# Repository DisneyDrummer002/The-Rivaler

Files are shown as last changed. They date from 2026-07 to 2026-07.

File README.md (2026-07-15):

# The Rivaler

The Rivaler is a multi-controller Arduino robot project with wireless remote control, stepper drive, line following, ultrasonic safety checks, a launcher mechanism, and camera/SD-card control.

> [!CAUTION]
> This project controls moving machinery and a launcher. Read the [safety requirements](docs/safety.md) before powering motors. The wireless software stop is not a substitute for a normally closed, latching physical emergency-stop circuit that removes motor power.

## Repository contents

| Path | Contents |
| --- | --- |
| [`firmware/giga_main_controller`](firmware/giga_main_controller) | Arduino GIGA drive, launcher, line-following, and ultrasonic-safety firmware |
| [`firmware/robot_nano_esp32`](firmware/robot_nano_esp32) | Robot-side Nano ESP32 wireless/UART bridge |
| [`firmware/remote_nano_esp32`](firmware/remote_nano_esp32) | Handheld remote firmware |
| [`firmware/mega_camera_controller`](firmware/mega_camera_controller) | Arduino Mega camera and SD-card controller |
| [`firmware/giga_stepper_test`](firmware/giga_stepper_test) | Standalone GIGA stepper-motor test sketch |
| [`firmware/shared`](firmware/shared) | Shared packet protocol and host-side protocol test |
| [`firmware/libraries/RivalerProtocol`](firmware/libraries/RivalerProtocol) | Arduino library wrapper for the shared protocol |
| [`mactest`](mactest) | Nano ESP32 utility sketch for printing a board's Wi-Fi MAC address |
| [`docs`](docs) | Wiring, protocol, line-following, camera, and safety documentation |
| [`BoM.xlsx`](BoM.xlsx) | Bill of materials |
| [`The Rivaler Connections.drawio.svg`](The%20Rivaler%20Connections.drawio.svg) | Editable Draw.io connection diagram in SVG form |
| [`Prompt Document for The Rivaler.docx`](Prompt%20Document%20for%20The%20Rivaler.docx) | Project prompt and design document |

## Hardware targets

- Arduino GIGA R1 WiFi: main controller and stepper test
- Two Arduino Nano ESP32 boards: remote and robot bridge
- Arduino Mega 2560: Arducam Mega B0401 and SD-card controller

See the [pin map](docs/pin-map.md) and the Draw.io connection diagram before wiring the boards.

## Build notes

Install [Arduino CLI](https://arduino.github.io/arduino-cli/) or use Arduino IDE 2. Install the Arduino Mbed OS GIGA Boards and Arduino ESP32 Boards platforms. The camera controller also requires the official `Arducam_Mega` library described in [the camera documentation](docs/mega-camera.md).

Example Arduino CLI commands for the sketches that do not require the camera library:

```sh
arduino-cli compile --fqbn arduino:mbed_giga:giga firmware/giga_main_controller
arduino-cli compile --fqbn arduino:mbed_giga:giga firmware/giga_stepper_test
arduino-cli compile --fqbn arduino:esp32:nano_nora firmware/robot_nano_esp32
arduino-cli compile --fqbn arduino:esp32:nano_nora firmware/remote_nano_esp32
```

Before uploading, review each sketch's `Config.h`, calibrate the line sensors as documented in [line following](docs/line-following.md), and verify the board addresses and physical wiring.

## Documentation

- [Pin map](docs/pin-map.md)
- [Packet protocol](docs/protocol.md)
- [Line following and calibration](docs/line-following.md)
- [Mega camera and SD card](docs/mega-camera.md)
- [Safety requirements](docs/safety.md)

## Project status

This is active hardware-development firmware. Test with drive wheels raised and launcher motor power disconnected before performing controlled, low-speed floor tests.

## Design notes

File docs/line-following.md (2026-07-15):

# Line Following

The GIGA implements line following as a separate drive mode. Pressing the
remote joystick button toggles the mode. A deliberate joystick movement,
remote timeout, emergency stop, wall warning, or missing-floor warning
cancels it immediately.

The controller independently normalizes the two analog sensors, applies
filtered proportional and derivative steering, slows for larger errors, and
keeps corrections within configured drive limits. If the line disappears, it
briefly continues at reduced speed, then pivots only toward the last observed
line direction. It stops if the line is not reacquired before the search
timeout.

## Sensor Placement

Place the two sensors close enough that the centered line produces a useful
signal on at least one sensor, preferably both. With only two sensors, a line
that passes invisibly through a wide gap between them cannot be distinguished
from a completely lost line.

## Calibration

Keep `kLineSensorCalibrationConfigured` set to `false` until calibration is
complete. The firmware will reject line-following activation in this state.

1. Disconnect motor power or raise the wheels clear of the work surface.
2. Set `kLineSensorCalibrationLoggingEnabled` to `true` and upload the GIGA
   firmware.
3. Hold both sensors over the normal floor. After the filtered readings settle,
   record several `Line sensors raw` values and average each sensor.
4. Repeat with both sensors over the line.
5. Put the four averages into the floor/line reading constants in the GIGA
   configuration. The line may read higher or lower than the floor.
6. Set `kLineSensorCalibrationConfigured` to `true` and calibration logging
   back to `false`.
7. With the robot supported and launcher power disconnected, verify that the
   Line Detected LED responds to the line before conducting a low-speed floor
   test.

The configured floor-to-line span must be at least
`kLineSensorMinimumCalibrationSpan` for each sensor. After basic operation is
verified, steering gains, cruise speed, loss timing, and detection strength can
be tuned in `Config.h` without changing the controller logic.

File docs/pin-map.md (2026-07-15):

# Rivaler Pin Map

This is the initial wiring map for firmware development. Inputs marked
`INPUT_PULLUP` connect to ground when activated. All boards sharing a signal
must share ground, but their power rails remain separate as shown in the
connection diagram.

## Remote Nano ESP32

| Pin | Connection |
| --- | --- |
| A0 | Joystick X |
| A1 | Joystick Y |
| D2 | Quick Shoot button |
| D3 | Rapid Fire button |
| D4 | Take Picture button |
| D5 | Eject SD button |
| D6 | Joystick push / Follow Line button |
| D7 | Launcher arm switch |
| D12 | Wireless software emergency-stop button |
| D8 | Active buzzer signal |
| D9 | Launcher Armed LED |
| D10 | Line Detected LED |
| D11 | Line Following LED |

The Remote Nano uses ESP-NOW with Robot Nano MAC
`3C:84:27:FC:EF:2C`. Its own MAC is `20:6E:F1:32:60:BC`.

The remote uses five discrete buttons: Quick Shoot, Rapid Fire, Take Picture,
Eject SD, and wireless emergency stop. The joystick push switch controls
Follow Line, and the separate switch controls launcher arming.

## Robot Nano ESP32

| Pin | Connection |
| --- | --- |
| D6 | UART RX from GIGA D14 / Serial4 TX3 |
| D7 | UART TX to GIGA D15 / Serial4 RX3 |
| D8 | UART TX to Mega D19 / RX1 |

The Mega-to-Nano UART return wire is intentionally absent.

## Arduino GIGA

| Pins | Connection |
| --- | --- |
| D3, D6 | Shield channel A: enable, speed |
| D4, D5 | Shield channel B: enable, speed |
| D7, D10 | Shield channel C: enable, speed |
| D8, D9 | Shield channel D: enable, speed |
| D14, D15 | Serial4 TX/RX for Robot Nano (board labels TX3/RX3), dedicated UART exception |
| A0, A1 | Left and right line sensors |
| D22, D23 | Front ultrasonic trigger/echo |
| D24, D25 | Downward ultrasonic trigger/echo |
| D26, D27 | Left ultrasonic trigger/echo |
| D28, D29 | Right ultrasonic trigger/echo |
| D30, D31 | Rear ultrasonic trigger/echo |
| D32 | 360-degree positional launcher magazine servo; homes at 0 degrees and indexes 45, 90, 135, 180, -45, -90, -135, then 0 |
| D33, D34, D35 | External launcher H-bridge: IN1, IN2, full-speed enable |

Connect the left bipolar stepper to shield channels A and B, and the right
bipolar stepper to channels C and D. The shield has no remaining H-bridge
channel for the launcher DC motor. The external H-bridge drives that motor
from D33, D34, and D35 instead.

The project's HC-SR04 modules have been verified operating at 3.3 V with the
GIGA, so their Echo signals connect directly to D23, D25, D27, D29, or D31.
The servo signal is D32, but servo power must come from its external supply
with a common ground to the GIGA.

## Arduino Mega

| Pins | Connection |
| --- | --- |
| D19 | UART RX from Robot Nano D8 |
| ICSP: 50/51/52 | Arducam Mega B0401 SPI: MISO/MOSI/SCK |
| D7 | Arducam B0401 chip select |
| ICSP: 50/51/52 | SD module shared SPI bus |
| D4 | SD module chip select |

The Robot Nano's 3.3 V TX signal is acceptable at Mega D19. Do not wire the
Mega's 5 V TX pin back to either Nano. Keep the inactive SPI device's chip
select HIGH to prevent camera/SD bus contention.

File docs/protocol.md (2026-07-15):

# Rivaler Packet Protocol

Protocol version 1 is the shared binary format for both ESP-NOW and UART.
It keeps the remote, bridge, GIGA, and camera controller aligned without
depending on ad-hoc text parsing.

## Packet layout

| Byte(s) | Field | Description |
| --- | --- | --- |
| 0 | Start | `0xA5` |
| 1 | Version | `1` |
| 2 | Type | Message type identifier |
| 3 | Sequence | Sender-local sequence; event retransmissions reuse their original value |
| 4 | Payload length | `0` through `24` |
| 5... | Payload | Binary payload for the packet type |
| Final | Checksum | XOR of bytes 1 through the final payload byte |

Only `6 + payload length` bytes are sent. Every receiver validates start byte,
version, exact received length, payload length, and checksum before acting.

## Transport routes

| Route | Direction | Message types |
| --- | --- | --- |
| Remote Nano ESP32 and Robot Nano ESP32 | Two-way ESP-NOW | Remote control, robot status, acknowledgement |
| Robot Nano ESP32 and Arduino GIGA | Two-way UART | Remote control, robot status, acknowledgement |
| Robot Nano ESP32 to Arduino Mega | One-way UART | Camera command |

The Remote Nano (`20:6E:F1:32:60:BC`) and Robot Nano
(`3C:84:27:FC:EF:2C`) are paired peers. ESP-NOW traffic is bidirectional;
the labels only identify each board's MAC address.

## Message payloads

### `kRemoteControl` (`0x10`)

| Field | Type | Meaning |
| --- | --- | --- |
| `joystickX` | signed 8-bit | `-100` to `100`; left/right command after dead-zone filtering |
| `joystickY` | signed 8-bit | `-100` to `100`; positive is forward |
| `heldButtons` | unsigned 16-bit flags | Current state of arm switch, line-follow button, and emergency stop |
| `edgeEvents` | unsigned 16-bit flags | One-time button presses: quick shoot, rapid fire, take picture, eject SD, line-follow press |

`heldButtons` is sent with every control packet. For packets containing
`edgeEvents`, the Remote Nano retransmits the same sequence until the Robot
Nano acknowledges receipt. The Robot Nano suppresses duplicate sequences, so
retransmission cannot stack launcher or camera actions.

### `kRobotStatus` (`0x20`)

| Field | Type | Meaning |
| --- | --- | --- |
| `statusFlags` | unsigned 16-bit flags | Launcher, line, safety, camera, and SD state |
| `frontDistanceCm` | unsigned 16-bit | Filtered front ultrasonic reading; `0` means unavailable |
| `groundDistanceCm` | unsigned 16-bit | Filtered downward sensor reading; `0` means unavailable |
| `safetyFault` | unsigned 8-bit | Current fail-safe reason, or `kNone` |

### `kCameraCommand` (`0x30`)

| Field | Type | Meaning |
| --- | --- | --- |
| `operation` | unsigned 8-bit enum | Capture burst or prepare SD eject |
| `photoCount` | unsigned 8-bit | Number of photos for a capture burst |
| `intervalMs` | unsigned 16-bit | Delay between photos |

The Robot Nano creates camera commands after receiving applicable remote
events. The Arduino Mega does not send command replies back over this link.

### `kAcknowledgement` (`0x40`)

| Field | Type | Meaning |
| --- | --- | --- |
| `acknowledgedSequence` | unsigned 8-bit | Sequence number being acknowledged |
| `accepted` | unsigned 8-bit | `1` when accepted, `0` when rejected |
| `rejectionReason` | unsigned 8-bit enum | `SafetyFault` value, otherwise `kNone` |

The Robot Nano acknowledges valid remote-control packets that contain one-shot
events. An acknowledgement means the bridge received the packet; it is not
permission to keep moving. The GIGA still stops drive motion and disarms the
launcher when valid remote control packets time out.

## Safety rules at the protocol boundary

- Receivers ignore malformed, stale, unknown-version, or checksum-invalid packets.
- A receiver must never fire or arm based on an incomplete packet.
- The Robot Nano forwards only valid remote-control packets to the GIGA.
- The GIGA is the final authority for drive, safety, arming, and any launcher action.
- The Mega accepts only valid camera-command packets and has no path to control the GIGA.

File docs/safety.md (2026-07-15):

# Safety Requirements

The remote's emergency-stop button on `D12` sends a wireless software stop.
It stops drive motion and disarms the launcher when the GIGA receives it, but
it is not a substitute for a physical emergency stop.

Install a separate normally closed, latching emergency-stop circuit that
removes power from the drive and launcher motor supplies. The circuit must
remain effective if any controller, radio link, or firmware component fails.

The launcher magazine uses positional commands across its configured
-180-degree through 180-degree range. It homes to 0 degrees at startup and
advances through the configured shooting positions. Verify its mechanical
alignment and full travel with launcher motor power disconnected before using
the firing controls.

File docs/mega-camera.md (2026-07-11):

# Mega Camera and SD

The Mega camera controller uses the official `Arducam_Mega` library for the
Arducam Mega B0401. Install that library from the Arduino IDE Library Manager
before compiling the Mega sketch. Do not substitute the older `ArduCAM` library.

The camera and SD card share the Mega hardware SPI bus on the ICSP header. The
camera chip-select is D7 and the SD chip-select is D4. Both are driven HIGH
whenever the other device is accessed.

Valid capture commands are processed as a nonblocking burst. The B0401 creates
QVGA JPEGs, each image is written as `RV00001.JPG` through `RV99999.JPG`, and
existing files are never overwritten. The default manual-photo command creates
10 images at 500 ms intervals. Camera, SD, malformed-JPEG, and receive-timeout
failures abort the active burst and are reported on the Mega USB serial console.

An SD-eject command waits only for the current image to finish, and cancels
any remaining images in the burst. It then closes the file, calls `SD.end()`,
deselects both SPI devices, and reports
`SD card is safe to remove.` on the Mega USB serial console. Further capture
requests are rejected until the Mega is restarted with the card installed.

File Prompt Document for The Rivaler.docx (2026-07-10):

Prompt Document for The Rivaler

You are Codex, an AI coding agent. I am building an advanced Arduino-based hobby robot called The Rivaler. Your job is to help generate, edit, and organize the firmware for this robot inside this GitHub repository.

This is an educational robotics project. The robot includes a small launcher that fires lightweight foam projectiles only at fixed inanimate targets in a controlled area. It must not be designed to target people or animals. Do not optimize the launcher for harm, range, injury, or destructive force. The launcher code must prioritize safety interlocks, manual arming, predictable behavior, and shutdown behavior.

The robot uses multiple Arduino boards, each with a specific role. Do not try to make one board do everything. Keep the architecture modular.

Rules

1. This repository will contain multiple firmware projects, documentation files, diagrams, BoM files, and 3D print files.

2. Do not read or analyze the entire repository every time you make a change.

3. Before editing, identify which files are relevant to the requested task.

4. Only inspect, create, or modify the files needed for the current task unless I explicitly tell you otherwise.

5. Do not modify unrelated firmware projects.

6. Do not modify 3D print files.

7. Before writing hardware-specific code, check the bill of materials spreadsheet and the connection diagram.

8. If exact pins are unclear, create clear placeholders in a Config.h file instead of guessing silently.

9. Keep the code organized into separate modules instead of one giant Arduino sketch.

10. Use readable names, comments, and clear state-machine logic.

11. Please include lots of debugging helps in each code.

12. Only use the items in the BOM. If you feel the need to add more things, let me know first. I will either approve it or deny it.

13. Do not skip things that you think you’ll leave me to do.

Major Hardware Roles

The robot uses four Arduino boards:

1. Remote Control Arduino Nano ESP32

This board is inside the handheld remote control.

Responsibilities:

- Read joystick position.

- Read buttons.

- Read launcher arm switch.

- Control remote status LEDs.

- Control the remote buzzer.

- Send user commands to the robot-side Nano ESP32 using ESP-NOW.

- Receive robot status messages from the robot-side Nano ESP32 using ESP-NOW.

2. Robot-Side Arduino Nano ESP32

This board is mounted on the robot and acts as the wireless bridge.

Responsibilities:

- Receive commands from the remote Nano ESP32 using ESP-NOW.

- Send robot status messages back to the remote Nano ESP32 using ESP-NOW.

- Communicate with the Arduino GIGA over UART in both directions.

- Send one-way camera commands to the Arduino Mega over UART.

- It should not control motors directly.

- It should not run the main robot logic.

- It should mostly translate wireless packets into wired robot commands and translate robot status into wireless status packets.

3. Arduino GIGA

This is the main robot controller.

Responsibilities:

- Read sensors connected to the main robot.

- Control the drive motors.

- Control the launcher-related actuator/servo.

- Control the launcher motor through the motor driver or motor shield.

- Run the main robot state machine.

- Handle joystick driving.

- Handle line detection.

- Handle line following mode.

- Handle wall/floor safety detection.

- Handle launcher arming logic.

- Handle quick shoot and rapid fire behavior.

- Send robot status back to the robot-side Nano ESP32.

4. Arduino Mega

This board is only for the camera and SD card system.

Responsibilities:

- Receive one-way commands from the robot-side Nano ESP32.

- Control the Arducam Mega.

- Save images to the SD card.

- Handle camera capture routines.

- Handle SD card eject/safe-stop command.

- Do not make the Mega responsible for driving, sensors, launcher logic, or remote logic.

Board-to-Board Communication

Use this communication architecture:

Remote Nano ESP32 <-> Robot Nano ESP32

- Protocol: ESP-NOW

- Direction: two-way

- Purpose: remote commands and robot status messages

Robot Nano ESP32 <-> Arduino GIGA

- Protocol: UART

- Direction: two-way

- Purpose: send remote commands to the GIGA and receive robot status from the GIGA

Robot Nano ESP32 -> Arduino Mega

- Protocol: UART

- Direction: one-way only

- Purpose: tell the Mega to take pictures or safely eject the SD card

- The Mega does not need to send data back to the Nano

- Do not require Mega TX to be connected

Grounding and Electrical Assumptions

The connection diagram only shows some ground connections for simplicity. In the real robot, all communicating boards and modules that share signals must share a common ground reference.

Do not assume power rails are shared just because grounds are shared.

Important:

- GIGA and Nano ESP32 are 3.3V logic systems.

- Mega is a 5V logic system.

- Since the Mega only receives from the Nano, Nano TX to Mega RX is acceptable in this design.

- Do not require Mega TX to connect to a 3.3V board.

- Motors must not be powered from Arduino GPIO pins.

- Servos and motors should use appropriate external power or drivers.

- Code should include safe startup states so motors and launcher outputs do not activate unexpectedly.

Terminology

When I say “Arduino Nano ESP32 transfer CR,” it means:

Remote Nano ESP32 -> ESP-NOW -> Robot Nano ESP32

This is command traffic from the controller to the robot.

When I say “Arduino Nano ESP32 transfer RC,” it means:

Robot Nano ESP32 -> ESP-NOW -> Remote Nano ESP32

This is status traffic from the robot back to the controller.

Core Robot Functions

1. Manual Driving

This should run continuously.

Flow:

- Remote reads joystick position.

- Remote Nano ESP32 sends joystick data to robot Nano ESP32 using ESP-NOW.

- Robot Nano ESP32 forwards joystick command to Arduino GIGA over UART.

- Arduino GIGA calculates how each wheel should move.

- Arduino GIGA drives the two 12V stepper motors through the motor control hardware.

Requirements:

- Use dead zones for joystick drift.

- Include speed limiting.

- Include safe stop behavior if communication is lost.

- If no valid joystick packet is received for a timeout period, stop the drive motors.

2. Launcher Arming

Flow:

- User turns on the launcher arm switch on the remote.

- Remote Nano ESP32 sends arm command to robot Nano ESP32 using ESP-NOW.

- Robot Nano ESP32 forwards arm command to Arduino GIGA.

- Arduino GIGA starts the launcher motor through the motor driver or shield.

- Wait 5000 ms.

- After the delay, the launcher is considered armed.

- Send status back to the remote.

- Remote turns on the Launcher Armed LED.

Requirements:

- Launcher must not fire unless armed.

- Launcher must have a disarmed state.

- On startup, launcher must always be disarmed.

- On communication loss or emergency condition, launcher should disarm.

- Do not allow accidental firing during boot.

3. Line Detection Status

This should run continuously.

Flow:

- Arduino GIGA reads analog IR sensors.

- Arduino GIGA determines whether the robot is currently detecting a line.

- Arduino GIGA sends line-detected status to the robot Nano ESP32.

- Robot Nano ESP32 sends status to remote Nano ESP32 using ESP-NOW.

- Remote turns Line Detected LED on or off.

Requirements:

- Use reasonable threshold constants in Config.h.

- Smooth/filter readings enough to avoid flickering.

- Keep line detection separate from line following mode.

4. Line Following Mode

Flow:

- If the robot detects that it is on a line and the user presses the Follow Line button, enter line following mode.

- Arduino GIGA follows the line using a typical line-following algorithm.

- While line following mode is active, the remote Line Following LED should be on.

- When the line ends completely or the button is pushed again (make sure there are no false positives by requiring it to be held for ½ second), line following mode should stop.

- When line following stops, the remote Line Following LED should turn off.

Requirements:

- Line following mode should be a state in the GIGA state machine.

- Manual joystick control should not fight line following mode.

- Include a way to exit line following mode if a safety condition is detected.

- If the front ultrasonic sensor detects a wall within 50 cm or the ground sensor detects no floor, stop line following immediately.

5. Wall and Floor Safety Detection

This should run continuously.

Flow:

- Arduino GIGA reads the front ultrasonic sensor.

- Arduino GIGA reads the ground-checking ultrasonic sensor.

- If a wall is detected within 50 cm, trigger warning.

- If the floor is not detected, trigger warning.

- Arduino GIGA sends warning status to robot Nano ESP32.

- Robot Nano ESP32 sends warning status to remote Nano ESP32 using ESP-NOW.

- Remote buzzer begins beeping.

- If line following mode is active, stop line following mode.

Requirements:

- Use configurable distance thresholds.

- Use filtering to avoid false triggers.

- Safety warnings should override line following.

- Safety warnings should be clearly sent to the remote.

6. Quick Shoot

Flow:

- User presses Quick Shoot button on the remote.

- Remote Nano ESP32 sends command to robot Nano ESP32.

- Robot Nano ESP32 forwards command to Arduino GIGA.

- Arduino GIGA checks whether launcher is armed.

- If launcher is armed, rotate the 360 servo 45 degrees.

- Return the servo to its original position.

- Robot Nano ESP32 also sends a command to Arduino Mega to begin photo capture.

Requirements:

- Quick Shoot must not run unless the launcher is armed.

- If launcher is not armed, ignore the command or send a rejected status.

- Servo timing should be controlled clearly.

- The Mega should be told to take pictures during the shooting event.

7. Rapid Fire

Flow:

- User presses Rapid Fire button on the remote.

- Remote Nano ESP32 sends command to robot Nano ESP32.

- Robot Nano ESP32 forwards command to Arduino GIGA.

- Arduino GIGA checks whether launcher is armed.

- If armed, perform 8 firing cycles.

- Each cycle should rotate the firing servo/action as needed.

- Wait 3 seconds between shots.

- During the shooting sequence, the robot Nano ESP32 should tell the Mega to take pictures.

- After all 8 shots, return the servo to its original position.

Important:

- Do not simply call Quick Shoot repeatedly if that would incorrectly reset the servo after every shot.

- Rapid Fire should have its own clear sequence logic.

- It must be interruptible by a safety stop or disarm condition.

8. Take Picture

Flow:

- When the Take Picture button is pressed on the remote, the command goes to the robot Nano ESP32.

- Robot Nano ESP32 sends a one-way camera command to the Arduino Mega.

- Arduino Mega takes 10 photos.

- Arduino Mega takes one photo every 0.5 seconds.

- Arduino Mega saves all images to the SD card.

Also:

- When Quick Shoot or Rapid Fire occurs, the robot Nano ESP32 should also command the Mega to take photos.

Requirements:

- Mega handles all camera and SD logic.

- Mega should not block any GIGA motor-control logic.

- File names should be unique.

- Include basic serial debug output on the Mega.

- Include safe handling if the SD card or camera fails.

9. Eject SD Card

Flow:

- User presses Eject SD Card button on the remote.

- Remote Nano ESP32 sends command to robot Nano ESP32.

- Robot Nano ESP32 sends a one-way command to Arduino Mega.

- Mega safely stops SD card activity so the robot can be powered off.

Requirements:

- Since the communication is one-way, do not require a reply from the Mega.

- Mega should stop writing files and flush/close anything needed before idle.

- Include serial debug messages on the Mega.

Suggested Firmware Organization

Use a structure like this unless the repository already has a better one:

firmware/

remote_nano_esp32/

remote_nano_esp32.ino

Config.h

RemoteInputs.h

RemoteInputs.cpp

EspNowRemote.h

EspNowRemote.cpp

StatusOutputs.h

StatusOutputs.cpp

robot_nano_esp32/

robot_nano_esp32.ino

Config.h

EspNowBridge.h

EspNowBridge.cpp

GigaSerialBridge.h

GigaSerialBridge.cpp

MegaCameraCommand.h

MegaCameraCommand.cpp

PacketProtocol.h

PacketProtocol.cpp

giga_main_controller/

giga_main_controller.ino

Config.h

RobotStateMachine.h

RobotStateMachine.cpp

DriveController.h

DriveController.cpp

LineSensors.h

LineSensors.cpp

LineFollower.h

LineFollower.cpp

UltrasonicSafety.h

UltrasonicSafety.cpp

LauncherController.h

LauncherController.cpp

PacketProtocol.h

PacketProtocol.cpp

mega_camera_controller/

mega_camera_controller.ino

Config.h

CameraManager.h

CameraManager.cpp

SDManager.h

SDManager.cpp

MegaCommandReceiver.h

MegaCommandReceiver.cpp

docs/

protocol.md

pin-map.md

safety.md

Communication Protocol Requirements

Use a clean packet protocol instead of random text strings when possible.

Suggested packet fields:

- Start byte

- Message type

- Payload length

- Payload

- Checksum

The protocol should support:

- joystick command

- button command

- arm launcher command

- disarm launcher command

- quick shoot command

- rapid fire command

- take picture command

- eject SD command

- line detected status

- line following active status

- launcher armed status

- safety warning status

- communication timeout status

Safety Requirements

The firmware must include these safety behaviors:

1. On startup, motors are stopped.

2. On startup, launcher is disarmed.

3. If communication from the remote is lost, drive motors stop.

4. If communication from the remote is lost, launcher should not fire.

5. Quick Shoot and Rapid Fire require launcher armed state.

6. Wall/floor warning should stop line following mode.

7. Any emergency or invalid state should fail safe.

8. Do not allow the robot to fire during boot.

9. Do not allow repeated commands to accidentally stack uncontrolled firing actions.

10. Use state variables instead of long blocking delay chains wherever possible.

Coding Style

Use:

- Clear classes/modules.

- Non-blocking timing with millis() when practical.

- Config.h files for pins and thresholds.

- Constants instead of magic numbers.

- Serial debug messages for bring-up and testing.

- State machines for robot modes.

- Comments explaining hardware assumptions.

Avoid:

- One giant .ino file.

- Blocking delays in main control loops, except where clearly acceptable.

- Hidden pin assumptions.

- Changing unrelated files.

- Re-reading the whole repository unnecessarily.

- Using the Mega for main robot logic.

- Sending Mega 5V TX into a 3.3V board.

- Optimizing the launcher for harm, range, or force.

Development Order

Build the code in this order:

1. Define shared message types and packet structure.

2. Create Config.h placeholders for each board.

3. Build remote Nano ESP32 input reading and ESP-NOW sending.

4. Build robot Nano ESP32 ESP-NOW receiving and UART forwarding.

5. Build GIGA receiving commands and basic drive control.

6. Build GIGA sensor status reporting.

7. Build remote status LED and buzzer outputs.

8. Build launcher arming state.

9. Build quick shoot.

10. Build rapid fire.

11. Build Mega one-way command receiver.

12. Build Mega Arducam + SD photo capture.

13. Build SD eject command.

14. Integrate safety timeouts.

15. Add documentation for pins, protocol, and testing.

Final Reminder

This project should be treated like a modular embedded robotics system. The goal is not to make the shortest code. The goal is to make code that is understandable, safe, testable, and separated by board responsibility.

Before making large changes, explain:

- Which files you need to inspect.

- Which files you plan to edit.

- Why those files are relevant.

Then make only the necessary changes.

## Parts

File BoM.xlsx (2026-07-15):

Item | Quantity | Link | Notes
12V NEMA 17 Stepper Motor | 2 |  | Main wheel motors. A swivel wheel is the 3rd point of contact
Arduino GIGA | 1 |  | Main brain
Arduino Mega | 1 |  | For taking pictures
Inland KS0448 Keyestudio L298P 4-Channel Motor Drive Shield | 1 | KS0448 Keyestudio L298P 4-Channel Motor Drive Shield — keyestudio WiKi documentation (https://docs.keyestudio.com/projects/KS0448/en/latest/docs/KS0448.html) | For controlling the steppers and servos
Arduino Nano ESP32 | 2 |  | For ESP NOW communication with the remote
5V USB Battery Pack | 3 |  | For powering the NANO ESP 32s and Mega
12V Battery Pack | 1 |  | For powering the giga and motors. Don't worry I know what I'm doing
SD Card Module | 1 | Amazon.com: WWZMDiB 3 Pcs Micro SD TF Card Adapter Reader Module with Logic Level Chip 3.3V 5V 6 Pin SPI Interface Compatible with for Arduino Raspberry Pi ESP32 : Electronics (https://www.amazon.com/WWZMDiB-Adater-Module-Support-Arduino/dp/B0B779R5TZ) | For storing the images
Buttons | 5 |  | Remote: Quick Shoot, Rapid Fire, Take Picture, Eject SD, and wireless emergency stop.
Joystick | 1 |  | Remote joystick axes plus Follow Line push switch.
Switches | 1 |  | Launcher arm switch on the remote.
Active Buzzer | 1 |  | For the remote control
Color LED | 3 |  | For the remote control
IR Sensors from Crunchlabs Domino Robot | 2 |  | These are for the line following system and are at the bottom. One is on the left. One is on the right.
Ultrasonic Sensors HC-SR04 | 5 |  | There will be one facing each direction. The one in the front and the one facing down are the only ones to worry about for now.
360 Servo from Sunfounder Picrawler | 1 |  | 360-degree positional magazine servo: homes at 0 degrees and indexes 45, 90, 135, 180, -45, -90, -135, then 0.
3V DC Motor | 1 |  | For spinning the launching mechanism.
External H-Bridge Motor Driver | 1 |  | Dedicated driver for the launcher 3V DC motor; digital enable runs it at full speed while armed.

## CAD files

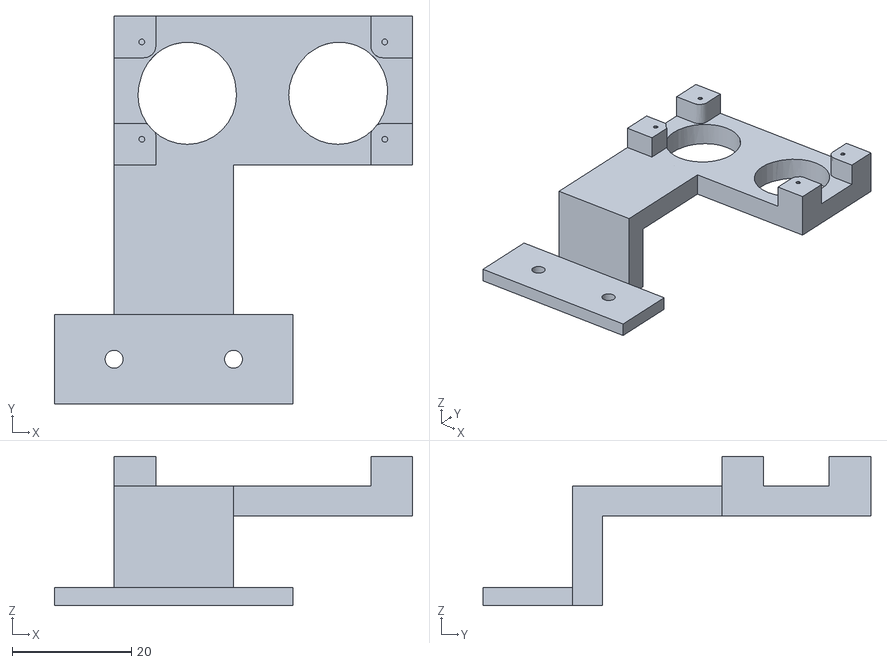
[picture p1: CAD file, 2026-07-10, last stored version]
3d Print Files/Ultrasonic Ground Mount.stl
60.0 x 65.0 x 25.0

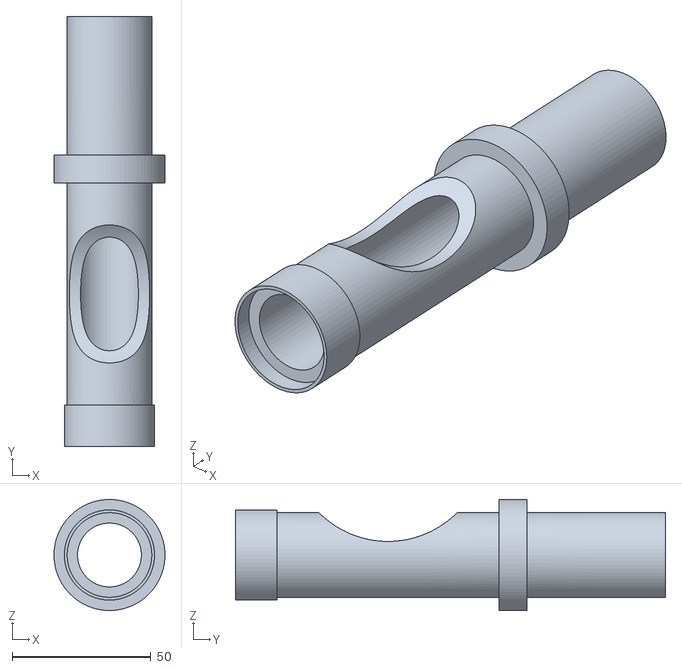
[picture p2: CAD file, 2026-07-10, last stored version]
3d Print Files/15 cm Barrel.stl
40.0 x 155.0 x 40.0

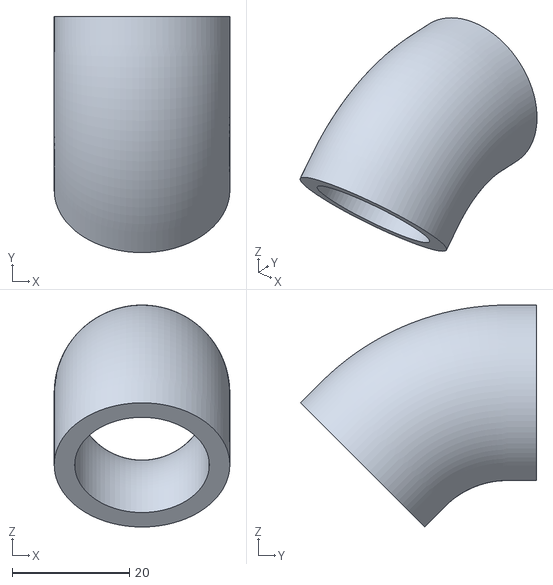
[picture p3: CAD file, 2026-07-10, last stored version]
3d Print Files/45 degree Barrel Attachment.stl
30.0 x 40.4 x 37.9

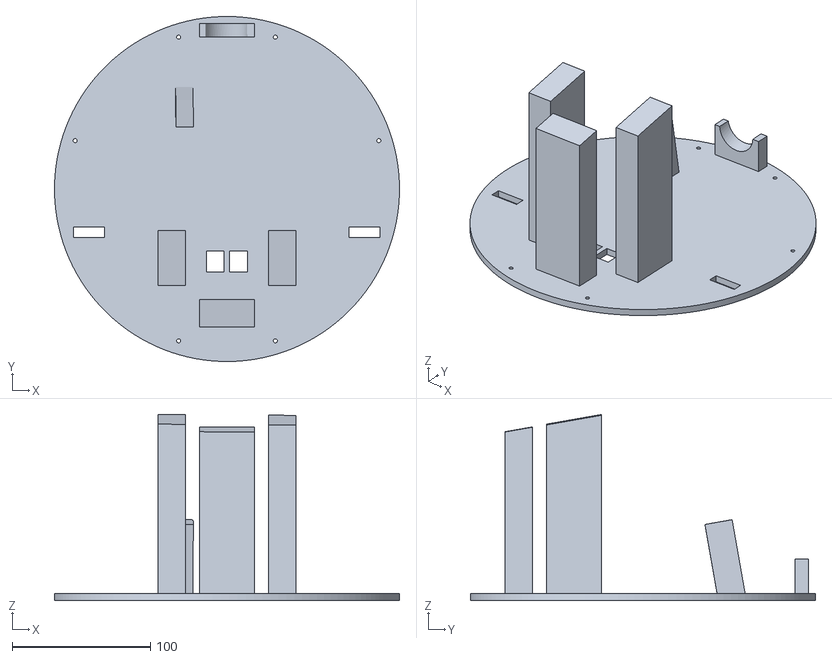
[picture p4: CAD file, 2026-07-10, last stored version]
3d Print Files/Top Chassis.stl
250.0 x 250.0 x 134.8

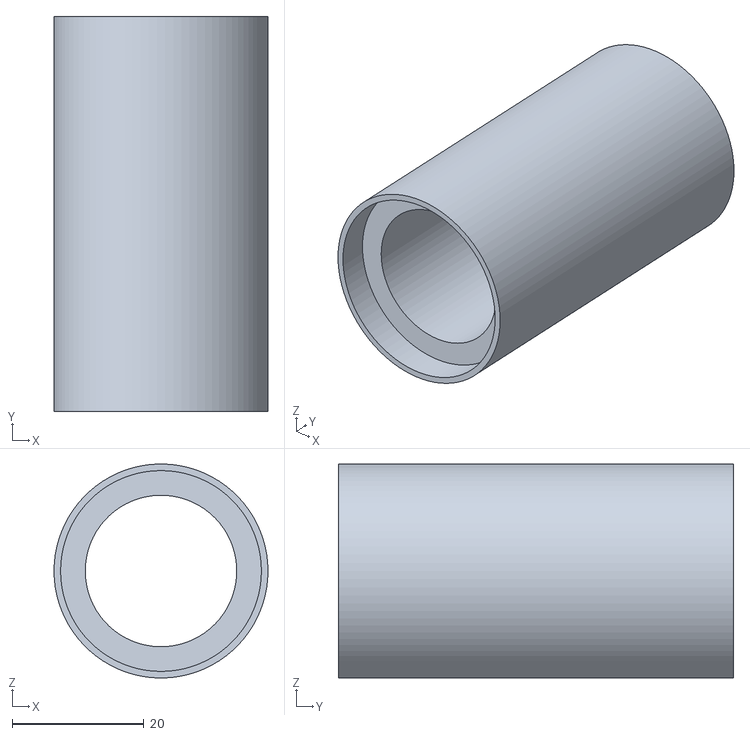
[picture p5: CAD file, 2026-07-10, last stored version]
3d Print Files/5 cm Barrel (2 Attachments).stl
32.5 x 60.0 x 32.5

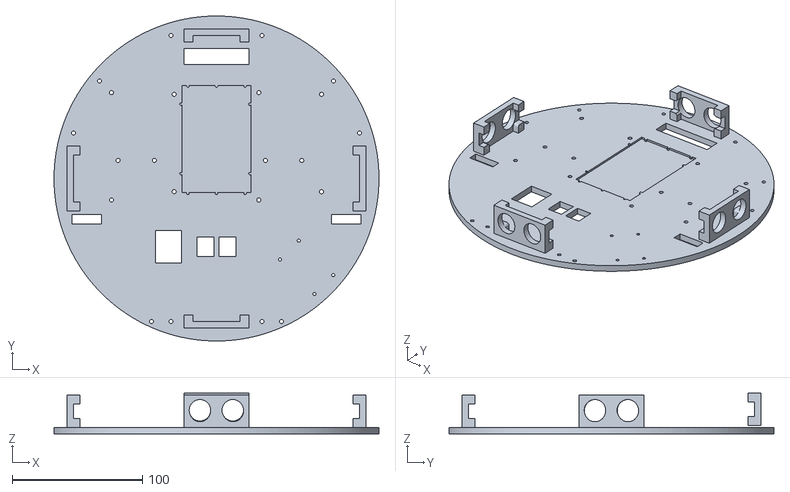
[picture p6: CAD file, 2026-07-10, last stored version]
3d Print Files/Middle Chassis.stl
250.0 x 250.0 x 31.5

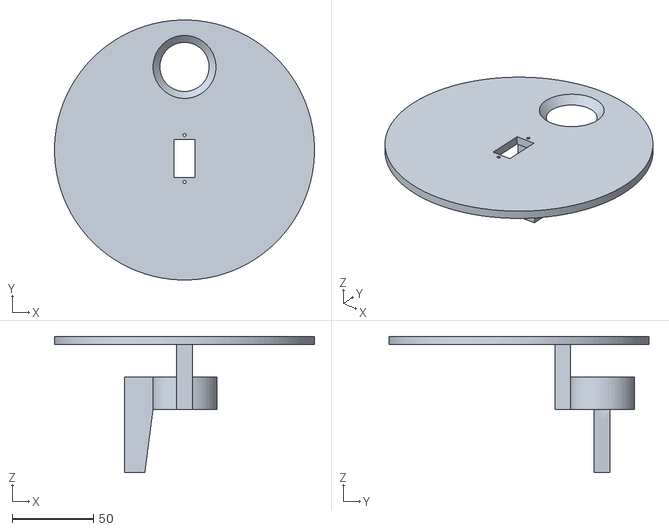
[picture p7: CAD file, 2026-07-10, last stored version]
3d Print Files/Motor Mount A.stl
160.0 x 160.0 x 83.9

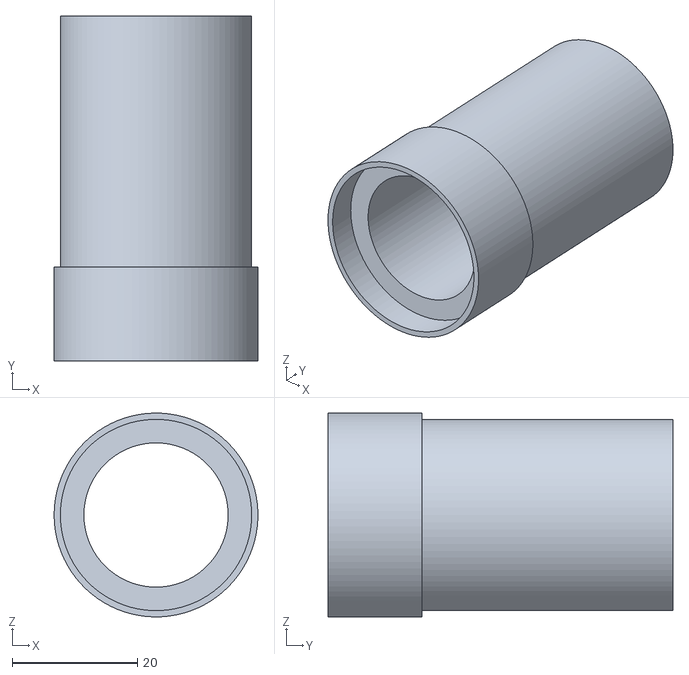
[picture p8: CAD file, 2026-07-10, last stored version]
3d Print Files/5 cm Barrel.stl
32.5 x 55.0 x 32.5

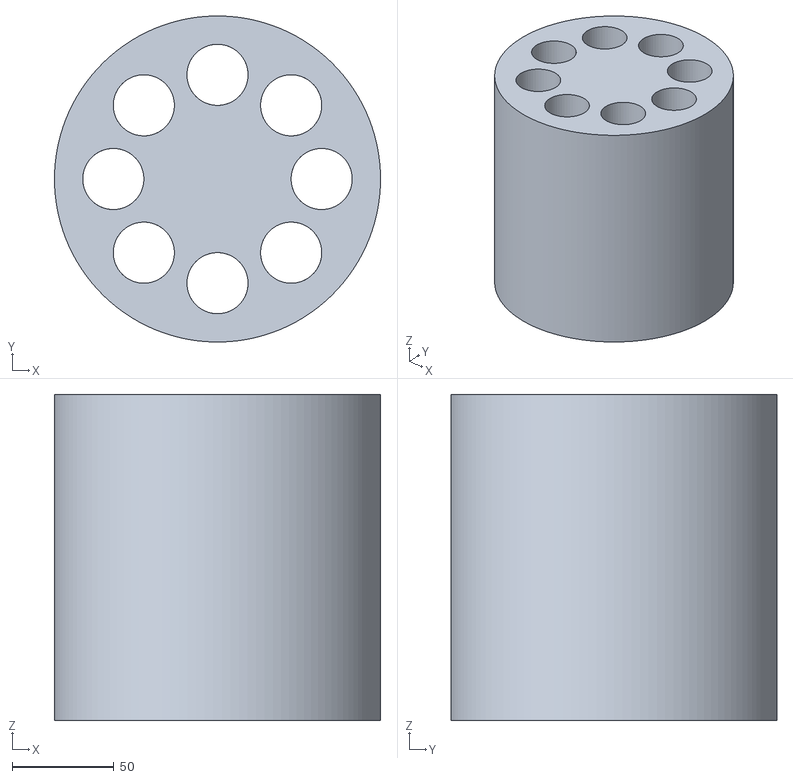
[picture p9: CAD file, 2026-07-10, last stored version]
3d Print Files/The MAG.stl
160.0 x 159.9 x 160.0

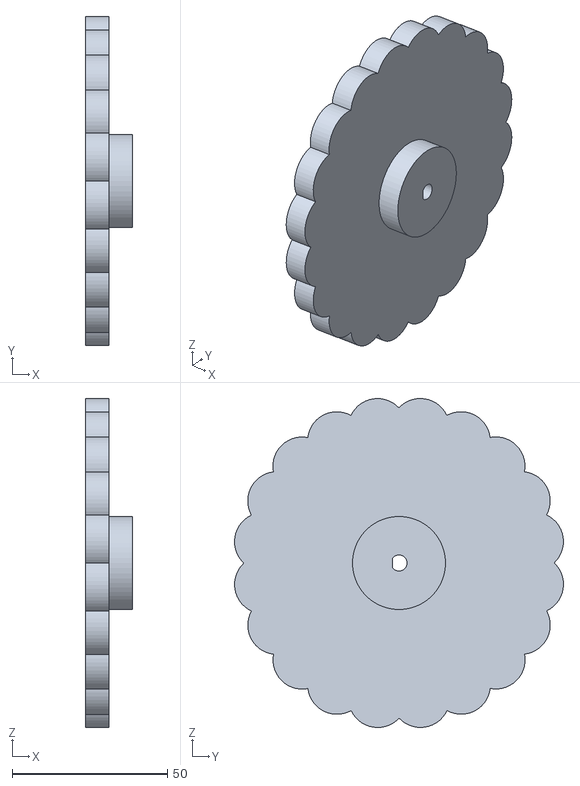
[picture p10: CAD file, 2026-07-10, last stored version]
3d Print Files/Wheel.stl
15.0 x 106.1 x 106.1

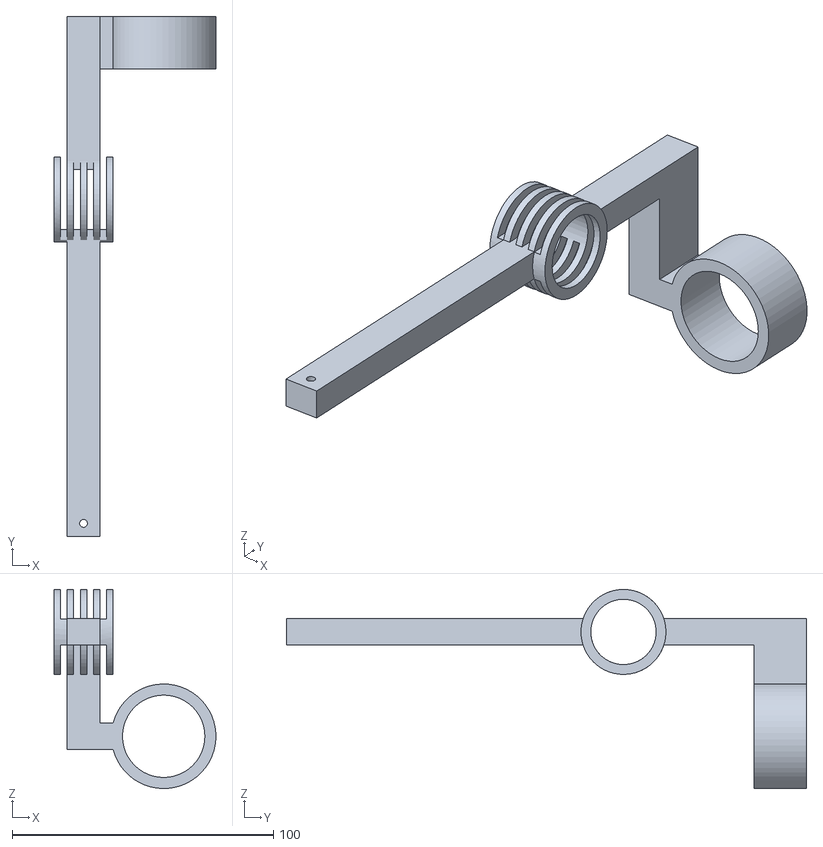
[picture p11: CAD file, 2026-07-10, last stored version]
3d Print Files/Motor Mount B.stl
61.9 x 198.9 x 76.2

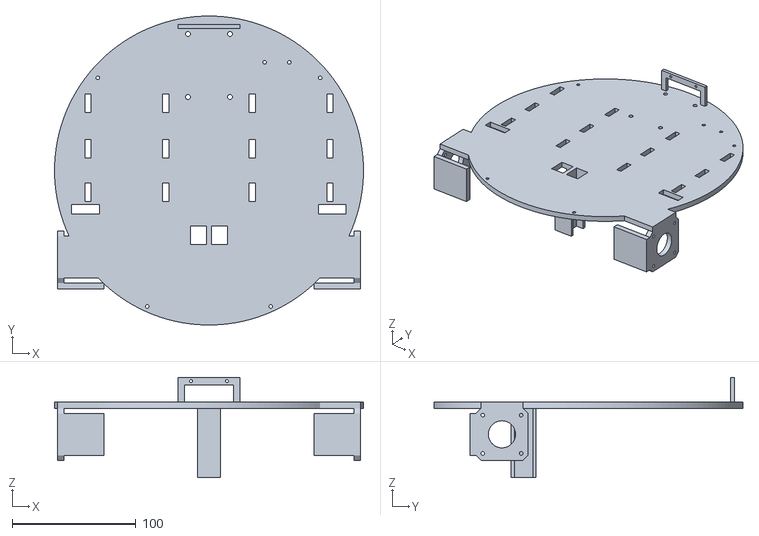
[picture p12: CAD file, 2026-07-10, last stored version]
3d Print Files/Bottom Chassis.stl
250.0 x 250.0 x 81.0

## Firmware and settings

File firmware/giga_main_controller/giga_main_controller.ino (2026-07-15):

#include "Config.h"
#include "DriveController.h"
#include "GigaCommandReceiver.h"
#include "LauncherController.h"
#include "LineFollower.h"
#include "LineSensors.h"
#include "UltrasonicSafety.h"

namespace {

// D14/D15 are the GIGA's Serial4 pins (TX3/RX3 on the board labels).
GigaCommandReceiver robotLink(Serial4);
DriveController driveController;
LauncherController launcherController;
LineFollower lineFollower;
LineSensors lineSensors;
UltrasonicSafety ultrasonicSafety;

bool hasReceivedControl = false;
bool emergencyStopActive = false;
bool remoteTimeoutActive = false;
bool launcherArmRequested = false;
unsigned long lastControlReceivedMs = 0;
unsigned long lastStatusTransmitMs = 0;
unsigned long lastLineCalibrationPrintMs = 0;
unsigned long lastUltrasonicDiagnosticPrintMs = 0;
uint8_t nextStatusSequence = 0;
unsigned long startupDriveTestStartedMs = 0;
bool startupDriveTestComplete = false;
bool remoteControlDiagnosticPending = false;
uint8_t remoteControlDiagnosticSequence = 0;
rivaler::RemoteControlPayload remoteControlDiagnostic{};

rivaler::SafetyFault activeSafetyFault() {
  if (remoteTimeoutActive) {
    return rivaler::SafetyFault::kRemoteTimeout;
  }
  if (emergencyStopActive) {
    return rivaler::SafetyFault::kEmergencyStop;
  }
  if (ultrasonicSafety.isNoFloorDetected()) {
    return rivaler::SafetyFault::kNoFloorDetected;
  }
  if (ultrasonicSafety.isWallTooClose()) {
    return rivaler::SafetyFault::kWallTooClose;
  }
  return rivaler::SafetyFault::kNone;
}

const char* safetyFaultName(rivaler::SafetyFault fault) {
  switch (fault) {
    case rivaler::SafetyFault::kNone:
      return "none";
    case rivaler::SafetyFault::kRemoteTimeout:
      return "remote-timeout";
    case rivaler::SafetyFault::kEmergencyStop:
      return "emergency-stop";
    case rivaler::SafetyFault::kWallTooClose:
      return "wall-too-close";
    case rivaler::SafetyFault::kNoFloorDetected:
      return "no-floor";
  }
  return "unknown";
}

void printUltrasonicDiagnostics(unsigned long nowMs) {
  if (!rivaler_giga_config::kUltrasonicDiagnosticLoggingEnabled ||
      ultrasonicSafety.isMeasurementInProgress() ||
      nowMs - lastUltrasonicDiagnosticPrintMs <
          rivaler_giga_config::kUltrasonicDiagnosticLogIntervalMs) {
    return;
  }

  lastUltrasonicDiagnosticPrintMs = nowMs;
  Serial.print("Ultrasonic: front=");
  Serial.print(ultrasonicSafety.frontDistanceCm());
  Serial.print(" cm, down=");
  Serial.print(ultrasonicSafety.groundDistanceCm());
  Serial.print(" cm, wall=");
  Serial.print(ultrasonicSafety.isWallTooClose() ? "STOP" : "clear");
  Serial.print(", floor=");
  Serial.print(ultrasonicSafety.isNoFloorDetected() ? "STOP" : "clear");
  Serial.print(", fault=");
  Serial.println(safetyFaultName(activeSafetyFault()));
}

void printRemoteControlDiagnostics() {
  if (!rivaler_giga_config::kRemoteControlDiagnosticLoggingEnabled ||
      !remoteControlDiagnosticPending ||
      ultrasonicSafety.isMeasurementInProgress()) {
    return;
  }

  remoteControlDiagnosticPending = false;
  Serial.print("Remote control: seq=");
  Serial.print(remoteControlDiagnosticSequence);
  Serial.print(", joystickX=");
  Serial.print(remoteControlDiagnostic.joystickX);
  Serial.print(", joystickY=");
  Serial.print(remoteControlDiagnostic.joystickY);
  Serial.print(", held=0x");
  Serial.print(remoteControlDiagnostic.heldButtons, HEX);
  Serial.print(", events=0x");
  Serial.println(remoteControlDiagnostic.edgeEvents, HEX);
}

void applyStartupDriveTest(unsigned long nowMs) {
  if (!rivaler_giga_config::kStartupDriveTestEnabled ||
      startupDriveTestComplete) {
    return;
  }

  if (nowMs - startupDriveTestStartedMs >=
      rivaler_giga_config::kStartupDriveTestDurationMs) {
    startupDriveTestComplete = true;
    driveController.stop();
    Serial.println("Startup drive test complete.");
    return;
  }

  if (activeSafetyFault() == rivaler::SafetyFault::kNone) {
    driveController.setJoystickCommand(
        0, rivaler_giga_config::kStartupDriveTestPercent);
  }
}

void processRobotCommands(unsigned long nowMs) {
  rivaler::Packet packet{};
  while (robotLink.readPacket(packet)) {
    if (packet.type != rivaler::MessageType::kRemoteControl) {
      continue;
    }

    rivaler::RemoteControlPayload control{};
    if (!rivaler::readPayload(packet, control)) {
      continue;
    }

    remoteControlDiagnostic = control;
    remoteControlDiagnosticSequence = packet.sequence;
    remoteControlDiagnosticPending = true;

    hasReceivedControl = true;
    lastControlReceivedMs = nowMs;
    remoteTimeoutActive = false;
    emergencyStopActive =
        (control.heldButtons & rivaler::kEmergencyStopHeld) != 0;
    launcherArmRequested =
        (control.heldButtons & rivaler::kArmSwitchHeld) != 0;

    const bool safetyStopActive =
        activeSafetyFault() != rivaler::SafetyFault::kNone;
    const bool followLineToggleRequested =
        (control.edgeEvents & rivaler::kFollowLinePressed) != 0;
    if (followLineToggleRequested) {
      if (lineFollower.isActive()) {
        lineFollower.deactivate();
        driveController.stop();
        Serial.println("Line following disabled.");
      } else if (safetyStopActive) {
        Serial.println("Line following rejected: safety stop is active.");
      } else if (lineFollower.activate(lineSensors, nowMs)) {
        driveController.stop();
        Serial.println("Line following enabled.");
      } else if (!lineSensors.isCalibrationValid()) {
        Serial.println("Line following rejected: sensors are not calibrated.");
      } else {
        Serial.println("Line following rejected: position the sensor array over the line.");
      }
    }

    const bool manualOverrideRequested =
        abs(control.joystickX) >=
            rivaler_giga_config::kLineFollowingManualOverridePercent ||
        abs(control.joystickY) >=
            rivaler_giga_config::kLineFollowingManualOverridePercent;
    if (lineFollower.isActive() && !followLineToggleRequested &&
        manualOverrideRequested) {
      lineFollower.deactivate();
      Serial.println("Line following disabled by joystick override.");
    }

    const bool quickShootRequested =
        (control.edgeEvents & rivaler::kQuickShootPressed) != 0;
    const bool rapidFireRequested =
        (control.edgeEvents & rivaler::kRapidFirePressed) != 0;
    if (rapidFireRequested && launcherArmRequested && !safetyStopActive &&
        !launcherController.requestRapidFire(nowMs)) {
      Serial.println("Rapid Fire ignored: launcher is not ready.");
    } else if (quickShootRequested && launcherArmRequested &&
               !safetyStopActive &&
               !launcherController.requestQuickShoot(nowMs)) {
      Serial.println("Quick Shoot ignored: launcher is not ready.");
    }

    if (safetyStopActive) {
      driveController.stop();
      continue;
    }

    if (!lineFollower.isActive()) {
      driveController.setJoystickCommand(control.joystickX, control.joystickY);
    }
  }
}

void printLineSensorCalibration(unsigned long nowMs) {
  if (!rivaler_giga_config::kLineSensorCalibrationLoggingEnabled ||
      nowMs - lastLineCalibrationPrintMs <
          rivaler_giga_config::kLineSensorCalibrationLogIntervalMs) {
    return;
  }

  lastLineCalibrationPrintMs = nowMs;
  const bool calibrationValid = lineSensors.isCalibrationValid();
  Serial.print("Left: analog=");
  Serial.print(lineSensors.leftReading());
  Serial.print(", line=");
  if (calibrationValid) {
    Serial.print(lineSensors.isLeftOnLine() ? "YES" : "NO");
  } else {
    Serial.print("UNCALIBRATED");
  }
  Serial.print(" | Right: analog=");
  Serial.print(lineSensors.rightReading());
  Serial.print(", line=");
  if (calibrationValid) {
    Serial.println(lineSensors.isRightOnLine() ? "YES" : "NO");
  } else {
    Serial.println("UNCALIBRATED");
  }
}

void applyControlTimeout(unsigned long nowMs) {
  const bool timedOut = hasReceivedControl &&
                        nowMs - lastControlReceivedMs >
                            rivaler_giga_config::kRemoteCommandTimeoutMs;
  if (!timedOut) {
    return;
  }

  if (!remoteTimeoutActive) {
    Serial.println("Remote command timeout: drive stopped.");
  }
  remoteTimeoutActive = true;
  emergencyStopActive = false;
  launcherArmRequested = false;
  driveController.stop();
}

void sendRobotStatus(unsigned long nowMs) {
  if (nowMs - lastStatusTransmitMs <
      rivaler_giga_config::kRobotStatusTransmitIntervalMs) {
    return;
  }

  rivaler::RobotStatusPayload status{};
  status.frontDistanceCm = ultrasonicSafety.frontDistanceCm();
  status.groundDistanceCm = ultrasonicSafety.groundDistanceCm();
  if (lineSensors.isLineDetected()) {
    status.statusFlags |= rivaler::kLineDetected;
  }
  if (lineFollower.isActive()) {
    status.statusFlags |= rivaler::kLineFollowingActive;
  }
  if (launcherController.isArmed()) {
    status.statusFlags |= rivaler::kLauncherArmed;
  }

  const rivaler::SafetyFault safetyFault = activeSafetyFault();
  if (safetyFault == rivaler::SafetyFault::kRemoteTimeout) {
    status.statusFlags |= rivaler::kRemoteLinkTimedOut;
    status.statusFlags |= rivaler::kSafetyWarning;
    status.safetyFault = safetyFault;
  } else if (safetyFault != rivaler::SafetyFault::kNone) {
    status.statusFlags |= rivaler::kSafetyWarning;
    status.safetyFault = safetyFault;
  }

  rivaler::Packet packet{};
  rivaler::initializePacket(packet, rivaler::MessageType::kRobotStatus,
                            nextStatusSequence++);
  if (rivaler::setPayload(packet, status)) {
    robotLink.sendPacket(packet);
  }

  lastStatusTransmitMs = nowMs;
}

}  // namespace

void setup() {
  Serial.begin(115200);
  delay(100);
  Serial.println("Rivaler GIGA controller starting.");

  robotLink.begin(rivaler_giga_config::kRobotNanoUartBaud);
  driveController.begin();
  startupDriveTestStartedMs = millis();
  launcherController.begin();
  lineSensors.begin();
  ultrasonicSafety.begin();

  if (!lineSensors.isCalibrationValid()) {
    Serial.println("Line following locked: sensor calibration is required.");
  }
}

void loop() {
  const unsigned long nowMs = millis();
  ultrasonicSafety.update(micros());
  lineSensors.update(nowMs);
  printUltrasonicDiagnostics(nowMs);
  printRemoteControlDiagnostics();
  printLineSensorCalibration(nowMs);
  processRobotCommands(nowMs);
  applyControlTimeout(nowMs);
  applyStartupDriveTest(nowMs);
  const bool safetyStopActive =
      activeSafetyFault() != rivaler::SafetyFault::kNone;
  if (safetyStopActive) {
    lineFollower.deactivate();
    driveController.stop();
  }
  launcherController.update(launcherArmRequested,
                            safetyStopActive, nowMs);
  if (!safetyStopActive) {
    lineFollower.update(lineSensors, driveController, nowMs);
  }
  driveController.update(micros());
  sendRobotStatus(nowMs);
}

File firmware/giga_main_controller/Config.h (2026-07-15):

#pragma once

#include <stdint.h>

namespace rivaler_giga_config {

constexpr int kUnassignedPin = -1;

// UART-only exception to the GIGA's D20-and-higher external GPIO convention.
// Serial4 uses D14/D15 (TX3/RX3 on the board labels); they are not
// general-purpose sensor pins.
constexpr unsigned long kRobotNanoUartBaud = 115200;
constexpr int kRobotNanoUartTxPin = 14;  // Serial4 TX, to Robot Nano D6.
constexpr int kRobotNanoUartRxPin = 15;  // Serial4 RX, from Robot Nano D7.
constexpr unsigned long kRemoteCommandTimeoutMs = 300;

// KS0448 L298P motor shield. These pins are fixed by the shield and must not
// be reused. Each bipolar stepper consumes two H-bridge channels.
constexpr int kMotorAEnablePin = 3;
constexpr int kMotorASpeedPin = 6;
constexpr int kMotorBEnablePin = 4;
constexpr int kMotorBSpeedPin = 5;
constexpr int kMotorCEnablePin = 7;
constexpr int kMotorCSpeedPin = 10;
constexpr int kMotorDEnablePin = 8;
constexpr int kMotorDSpeedPin = 9;

// Wire the left stepper to shield channels A and B, and the right stepper to
// channels C and D. Direction is corrected during the first wheel test.
constexpr int kLeftStepperCoil1EnablePin = kMotorAEnablePin;
constexpr int kLeftStepperCoil1SpeedPin = kMotorASpeedPin;
constexpr int kLeftStepperCoil2EnablePin = kMotorBEnablePin;
constexpr int kLeftStepperCoil2SpeedPin = kMotorBSpeedPin;
constexpr int kRightStepperCoil1EnablePin = kMotorCEnablePin;
constexpr int kRightStepperCoil1SpeedPin = kMotorCSpeedPin;
constexpr int kRightStepperCoil2EnablePin = kMotorDEnablePin;
constexpr int kRightStepperCoil2SpeedPin = kMotorDSpeedPin;

// The approved A/B-left and C/D-right channel plan is active. Motors remain
// stopped until a valid joystick command arrives from the remote.
constexpr bool kDriveOutputsEnabled = true;
constexpr int8_t kMaximumDriveCommandPercent = 60;
constexpr int8_t kDriveJoystickDeadbandPercent = 12;
constexpr bool kStartupDriveTestEnabled = true;
constexpr unsigned long kStartupDriveTestDurationMs = 1000;
constexpr int8_t kStartupDriveTestPercent = 60;
constexpr bool kLeftDriveDirectionReversed = false;
constexpr bool kRightDriveDirectionReversed = false;
// Spread each joystick reading across its nominal 50 ms update window. The
// full-speed interval is currently 4 ms; lower commands receive proportionally
// fewer, more widely spaced steps for smooth differential steering.
constexpr unsigned long kStepperStepIntervalUs = 4000;
constexpr unsigned long kDriveCommandWindowUs = 50000;
constexpr uint16_t kStepperStepsPerCommandUpdate =
    kDriveCommandWindowUs / kStepperStepIntervalUs;
constexpr uint16_t kStepperMaximumQueuedSteps =
    kStepperStepsPerCommandUpdate * 2;
// Channels A/B remain ordinary digital enables. Only channels C/D use PWM.
constexpr uint8_t kChannelsCdEnablePwm = 255;
constexpr unsigned long kRobotStatusTransmitIntervalMs = 250;

// Dedicated external H-bridge for the launcher DC motor. The enable line is
// digital and drives the motor at full speed while armed.
constexpr bool kLauncherMotorDriverConfigured = true;
constexpr int kLauncherMotorInputAPin = 33;
constexpr int kLauncherMotorInputBPin = 34;
constexpr int kLauncherMotorEnablePin = 35;

// The magazine uses a 360-degree positional servo. Signed magazine angles are
// mapped directly to the servo's full pulse range; zero is the startup home.
constexpr int kLauncherServoPin = 11;
constexpr int16_t kLauncherServoMinimumAngleDeg = -180;
constexpr int16_t kLauncherServoMaximumAngleDeg = 180;
constexpr int16_t kLauncherServoHomeAngleDeg = 0;
constexpr uint16_t kLauncherServoMinimumPulseUs = 500;
constexpr uint16_t kLauncherServoMaximumPulseUs = 2500;
constexpr unsigned long kLauncherServoSettleDurationMs = 350;

// Analog pins do not conflict with the shield's fixed motor-control pins.
constexpr int kLeftLineSensorPin = A0;
constexpr int kRightLineSensorPin = A1;
constexpr uint8_t kLineSensorAdcResolutionBits = 12;
constexpr unsigned long kLineSensorSampleIntervalMs = 10;
constexpr uint8_t kLineSensorFilterDivisor = 4;

// Fill these four readings during bring-up. Each sensor needs an average raw
// reading over the normal floor and over the line. Either polarity is valid.
constexpr bool kLineSensorCalibrationConfigured = true;
constexpr uint16_t kLeftLineSensorFloorReading = 275;
constexpr uint16_t kLeftLineSensorLineReading = 4000;
constexpr uint16_t kRightLineSensorFloorReading = 275;
constexpr uint16_t kRightLineSensorLineReading = 4000;
constexpr uint16_t kLineSensorMinimumCalibrationSpan = 200;
constexpr uint16_t kLineDetectedStrength = 350;  // 0 to 1000.
constexpr unsigned long kLineSensorStaleTimeoutMs = 100;
constexpr bool kLineSensorCalibrationLoggingEnabled = true;
constexpr unsigned long kLineSensorCalibrationLogIntervalMs = 250;
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

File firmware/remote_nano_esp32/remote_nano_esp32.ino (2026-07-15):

#include "Config.h"
#include "EspNowRemote.h"
#include "RemoteInputs.h"
#include "StatusOutputs.h"

namespace {

RemoteInputs remoteInputs;
EspNowRemote espNowRemote;
StatusOutputs statusOutputs;

uint8_t nextSequence = 0;
bool eventAcknowledgementPending = false;
uint8_t pendingEventSequence = 0;
uint16_t pendingEventMask = 0;
unsigned long lastControlTransmitMs = 0;
unsigned long lastDebugPrintMs = 0;
bool radioReady = false;
uint16_t lastReportedHeldButtons = 0;

void printEventNames(uint16_t events) {
  bool needsSeparator = false;
  const auto printName = [&needsSeparator](const char* name) {
    if (needsSeparator) {
      Serial.print(", ");
    }
    Serial.print(name);
    needsSeparator = true;
  };

  if ((events & rivaler::kQuickShootPressed) != 0) {
    printName("Quick Shoot");
  }
  if ((events & rivaler::kRapidFirePressed) != 0) {
    printName("Rapid Fire");
  }
  if ((events & rivaler::kTakePicturePressed) != 0) {
    printName("Take Picture");
  }
  if ((events & rivaler::kEjectSdPressed) != 0) {
    printName("SD Eject");
  }
  if ((events & rivaler::kFollowLinePressed) != 0) {
    printName("Follow Line");
  }
}

void printHeldButtonChanges(uint16_t previousButtons, uint16_t currentButtons) {
  const uint16_t changedButtons = previousButtons ^ currentButtons;
  if (changedButtons == 0) {
    return;
  }

  Serial.print("Input: ");
  bool needsSeparator = false;
  const auto printChange = [&currentButtons, &needsSeparator](uint16_t bit,
                                                                const char* name) {
    if (needsSeparator) {
      Serial.print(", ");
    }
    Serial.print(name);
    Serial.print((currentButtons & bit) != 0 ? " ON" : " OFF");
    needsSeparator = true;
  };

  if ((changedButtons & rivaler::kArmSwitchHeld) != 0) {
    printChange(rivaler::kArmSwitchHeld, "Arm switch");
  }
  if ((changedButtons & rivaler::kFollowLineHeld) != 0) {
    printChange(rivaler::kFollowLineHeld, "Follow Line");
  }
  if ((changedButtons & rivaler::kEmergencyStopHeld) != 0) {
    printChange(rivaler::kEmergencyStopHeld, "Emergency stop");
  }
  Serial.println();
}

const char* safetyFaultName(rivaler::SafetyFault fault) {
  switch (fault) {
    case rivaler::SafetyFault::kRemoteTimeout:
      return "remote timeout";
    case rivaler::SafetyFault::kWallTooClose:
      return "wall too close";
    case rivaler::SafetyFault::kNoFloorDetected:
      return "no floor detected";
    case rivaler::SafetyFault::kEmergencyStop:
      return "emergency stop";
    case rivaler::SafetyFault::kInvalidCommand:
      return "invalid command";
    case rivaler::SafetyFault::kNone:
    default:
      return "no fault reported";
  }
}

void sendCurrentControl(unsigned long nowMs) {
  uint8_t sequence = 0;
  uint16_t events = 0;
  bool isNewEventPacket = false;
  if (eventAcknowledgementPending) {
    sequence = pendingEventSequence;
    events = pendingEventMask;
  } else {
    sequence = nextSequence++;
    if (remoteInputs.pendingEvents() != 0) {
      events = remoteInputs.pendingEvents();
      pendingEventMask = events;
      pendingEventSequence = sequence;
      eventAcknowledgementPending = true;
      isNewEventPacket = true;
    }
  }

  rivaler::RemoteControlPayload control =
      remoteInputs.createControlPayload(events);
  rivaler::Packet packet{};
  rivaler::initializePacket(packet, rivaler::MessageType::kRemoteControl,
                            sequence);
  if (!rivaler::setPayload(packet, control)) {
    return;
  }

  const uint16_t changedHeldButtons =
      control.heldButtons ^ lastReportedHeldButtons;
  if (changedHeldButtons != 0) {
    printHeldButtonChanges(lastReportedHeldButtons, control.heldButtons);
    lastReportedHeldButtons = control.heldButtons;
  }

  if (isNewEventPacket) {
    Serial.print("Input: ");
    printEventNames(events);
    Serial.println(" pressed.");
  }

  const bool queued = espNowRemote.sendRemoteControl(packet);
  if (isNewEventPacket || changedHeldButtons != 0) {
    Serial.print("ESP-NOW packet ");
    Serial.print(sequence);
    Serial.println(queued ? " queued for transmission."
                          : " was not queued; control sending will retry.");
    if (queued && isNewEventPacket) {
      Serial.println("Waiting for Robot Nano acknowledgement.");
    }
  }

  lastControlTransmitMs = nowMs;
}

void processAcknowledgements() {
  rivaler::AcknowledgementPayload acknowledgement{};
  while (espNowRemote.takeLatestAcknowledgement(acknowledgement)) {
    if (!eventAcknowledgementPending ||
        acknowledgement.acknowledgedSequence != pendingEventSequence) {
      continue;
    }

    Serial.print("Robot Nano acknowledgement for ");
    printEventNames(pendingEventMask);
    if (!acknowledgement.accepted) {
      Serial.print(" rejected: ");
      Serial.println(safetyFaultName(acknowledgement.rejectionReason));
      continue;
    }
    Serial.println(" received.");

    remoteInputs.acknowledgeEvents(pendingEventMask);
    pendingEventMask = 0;
    eventAcknowledgementPending = false;
  }
}

void printDebugStatus(unsigned long nowMs) {
  if (nowMs - lastDebugPrintMs < 1000) {
    return;
  }

  lastDebugPrintMs = nowMs;
  Serial.print("ESP-NOW status link: ");
  Serial.println(espNowRemote.hasHealthyStatusLink(nowMs) ? "healthy"
                                                          : "waiting");
}

}  // namespace

void setup() {
  Serial.begin(115200);
  delay(100);
  Serial.println("Rivaler remote starting.");

  remoteInputs.begin();
  lastReportedHeldButtons = remoteInputs.createControlPayload(0).heldButtons;
  statusOutputs.begin();
  radioReady = espNowRemote.begin();
}

void loop() {
  const unsigned long nowMs = millis();
  remoteInputs.update(nowMs);
  processAcknowledgements();

  rivaler::RobotStatusPayload status{};
  if (espNowRemote.takeLatestRobotStatus(status)) {
    statusOutputs.applyRobotStatus(status);
  }
  statusOutputs.setStatusLinkHealthy(
      radioReady && espNowRemote.hasHealthyStatusLink(nowMs));
  statusOutputs.update(nowMs);

  if (radioReady && nowMs - lastControlTransmitMs >=
                        rivaler_remote_config::kControlTransmitIntervalMs) {
    sendCurrentControl(nowMs);
  }

  printDebugStatus(nowMs);
}

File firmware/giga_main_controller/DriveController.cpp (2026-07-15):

#include "DriveController.h"

#include "Config.h"

using namespace rivaler_giga_config;

namespace {

constexpr bool kFullStepPhases[4][2] = {
    {false, true},
    {false, false},
    {true, false},
    {true, true},
};

}  // namespace

void DriveController::begin() {
  analogWriteResolution(8);

  leftStepper_ = {kLeftStepperCoil1EnablePin,
                  kLeftStepperCoil1SpeedPin,
                  kLeftStepperCoil2EnablePin,
                  kLeftStepperCoil2SpeedPin,
                  0,
                  0,
                  0,
                  0,
                  kStepperStepIntervalUs,
                  false,
                  false,
                  kLeftDriveDirectionReversed};
  rightStepper_ = {kRightStepperCoil1EnablePin,
                   kRightStepperCoil1SpeedPin,
                   kRightStepperCoil2EnablePin,
                   kRightStepperCoil2SpeedPin,
                   0,
                   0,
                   0,
                   0,
                   kStepperStepIntervalUs,
                   true,
                   false,
                   kRightDriveDirectionReversed};

  const StepperState* steppers[] = {&leftStepper_, &rightStepper_};
  for (const StepperState* stepper : steppers) {
    pinMode(stepper->coil1DirectionPin, OUTPUT);
    pinMode(stepper->coil1EnablePin, OUTPUT);
    pinMode(stepper->coil2DirectionPin, OUTPUT);
    pinMode(stepper->coil2EnablePin, OUTPUT);
  }

  releaseStepper(leftStepper_);
  releaseStepper(rightStepper_);
}

void DriveController::setJoystickCommand(int8_t joystickX, int8_t joystickY) {
  const int x = clampPercent(joystickX);
  const int y = clampPercent(joystickY);
  const int xMagnitude = abs(x);
  const int yMagnitude = abs(y);

  if (xMagnitude <= kDriveJoystickDeadbandPercent &&
      yMagnitude <= kDriveJoystickDeadbandPercent) {
    setMotorCommands(0, 0);
    return;
  }

  // Restore continuous differential mixing. Diagonal joystick positions make
  // one wheel take fewer, more widely spaced steps instead of collapsing the
  // command to forward/backward/spin-only choices.
  setMotorCommands(y + x, y - x);
}

void DriveController::setSteeringCommand(int8_t steeringPercent,
                                         int8_t forwardPercent) {
  const int steering = clampPercent(steeringPercent);
  const int forward = clampPercent(forwardPercent);
  setMotorCommands(forward + steering, forward - steering);
}

void DriveController::update(unsigned long nowUs) {
  if (!kDriveOutputsEnabled) {
    releaseStepper(leftStepper_);
    releaseStepper(rightStepper_);
    return;
  }

  updateStepper(leftStepper_, nowUs);
  updateStepper(rightStepper_, nowUs);
}

void DriveController::stop() {
  leftStepper_.commandPercent = 0;
  leftStepper_.queuedSteps = 0;
  rightStepper_.commandPercent = 0;
  rightStepper_.queuedSteps = 0;
}

int DriveController::clampPercent(int value) {
  return constrain(value, -kMaximumDriveCommandPercent,
                   kMaximumDriveCommandPercent);
}

void DriveController::setMotorCommands(int leftPercent, int rightPercent) {
  queueMotorCommand(leftStepper_, leftPercent);
  queueMotorCommand(rightStepper_, rightPercent);
}

void DriveController::queueMotorCommand(StepperState& stepper,
                                        int commandPercent) {
  const int command = clampPercent(commandPercent);
  if (command == 0) {
    stepper.commandPercent = 0;
    stepper.queuedSteps = 0;
    return;
  }

  const bool directionChanged =
      stepper.commandPercent != 0 &&
      ((stepper.commandPercent > 0) != (command > 0));
  if (directionChanged) {
    stepper.queuedSteps = 0;
  }

  stepper.commandPercent = command;
  const uint32_t commandMagnitude = static_cast<uint32_t>(abs(command));
  const uint16_t stepsForUpdate = static_cast<uint16_t>(max(
      1UL,
      (static_cast<uint32_t>(kStepperStepsPerCommandUpdate) *
           commandMagnitude +
       kMaximumDriveCommandPercent - 1) /
          kMaximumDriveCommandPercent));
  stepper.stepIntervalUs = max(
      kStepperStepIntervalUs,
      (kStepperStepIntervalUs *
       static_cast<unsigned long>(kMaximumDriveCommandPercent)) /
          commandMagnitude);
  const uint32_t expandedQueue =
      static_cast<uint32_t>(stepper.queuedSteps) +
      stepsForUpdate;
  stepper.queuedSteps = static_cast<uint16_t>(
      min(expandedQueue, static_cast<uint32_t>(kStepperMaximumQueuedSteps)));
}

void DriveController::enableStepper(StepperState& stepper) {
  if (stepper.usePwmEnable) {
    analogWrite(stepper.coil1EnablePin, kChannelsCdEnablePwm);
    analogWrite(stepper.coil2EnablePin, kChannelsCdEnablePwm);
  } else {
    digitalWrite(stepper.coil1EnablePin, HIGH);
    digitalWrite(stepper.coil2EnablePin, HIGH);
  }
  stepper.energized = true;
}

void DriveController::releaseStepper(StepperState& stepper) {
  if (stepper.usePwmEnable) {
    analogWrite(stepper.coil1EnablePin, 0);
    analogWrite(stepper.coil2EnablePin, 0);
  } else {
    digitalWrite(stepper.coil1EnablePin, LOW);
    digitalWrite(stepper.coil2EnablePin, LOW);
  }
  digitalWrite(stepper.coil1DirectionPin, LOW);
  digitalWrite(stepper.coil2DirectionPin, LOW);
  stepper.queuedSteps = 0;
  stepper.energized = false;
}

void DriveController::applyPhase(StepperState& stepper) {
  digitalWrite(stepper.coil1DirectionPin,
               kFullStepPhases[stepper.phaseIndex][0]);
  digitalWrite(stepper.coil2DirectionPin,
               kFullStepPhases[stepper.phaseIndex][1]);
}

void DriveController::updateStepper(StepperState& stepper, unsigned long nowUs) {
  int command = stepper.commandPercent;
  if (stepper.directionReversed) {
    command = -command;
  }

  if (command == 0 || stepper.queuedSteps == 0) {
    // Keep the last applied phase energized so the wheel remains locked and
    // motion can resume from the same point in the sequence.
    return;
  }

  if (!stepper.energized) {
    applyPhase(stepper);
    enableStepper(stepper);
    stepper.lastStepUs = nowUs;
    return;
  }

  if (nowUs - stepper.lastStepUs < stepper.stepIntervalUs) {
    return;
  }

  stepper.phaseIndex =
      (stepper.phaseIndex + (command > 0 ? 1 : 3)) % 4;
  applyPhase(stepper);
  --stepper.queuedSteps;
  // Resynchronize after every step instead of emitting rapid catch-up steps
  // after a slow sensor or communication pass.
  stepper.lastStepUs = nowUs;
}

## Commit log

2026-07-10 First attempt for the prompt
    [15 cm Barrel.stl, 45 degree Barrel Attachment.stl, 5 cm Barrel (2 Attachments).stl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]
2026-07-10 Ready to start with Codex
    [15 cm Barrel.stl, 45 degree Barrel Attachment.stl, 5 cm Barrel (2 Attachments).stl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]
2026-07-11 The Chat GPT Grind
    Files were created and edited. Mistakes may have been made.
    [BoM.xlsx]
2026-07-15 Almost Ready to Release
    [BoM.xlsx]
